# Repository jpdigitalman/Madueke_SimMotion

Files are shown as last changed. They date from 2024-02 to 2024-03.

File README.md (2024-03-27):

# Madueke_Sim (6DOF): Open Source ESP32 Controlled Servo Motor Board (AMC-AASD15A)

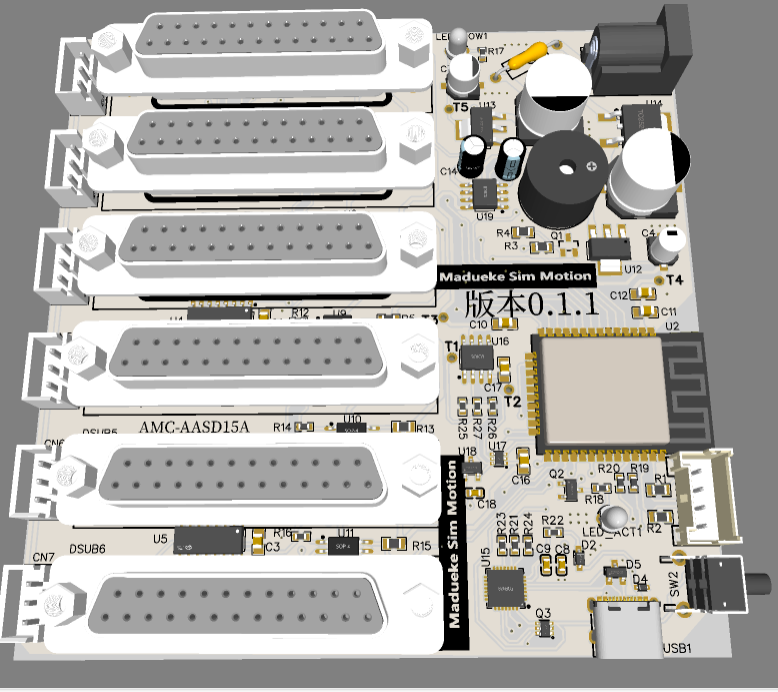
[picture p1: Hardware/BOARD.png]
Madueke_Sim Schematic


Welcome to Madueke_Sim (6DOF), an open-source project revolutionizing motion simulation! Our project utilizes the powerful ESP32 microcontroller to control six servo motors, providing a seamless and immersive experience for motion simulation enthusiasts.

## Features:

- **ESP32 Compatibility**: Our board is designed to seamlessly integrate with ESP32 microcontrollers, offering robust performance and versatility.
  
- **Plug and Play Servo Driver Support**: The board supports AASD-15A servo driver plug and play functionality, making setup a breeze.
  
- **Open Hardware**: We believe in transparency and collaboration. The board's schematic, PCB layout, and Bill of Materials (BOM) are all open-source, empowering users to customize and improve the design.

- **Versatile Firmware**: Our Arduino-based firmware supports various configurations, including 6-DOF, 3-DOF plus Yaw, and 4-DOF plus Yaw, catering to different motion simulation needs.

- **Sample Web Application**: Experience our motion simulation firsthand with our free source code for the firmware, which includes a sample web application. Test all motor movements effortlessly and explore the capabilities of Madueke_Sim (6DOF).

- **Advanced Firmware**: For enthusiasts seeking even more features, our advanced firmware, available upon request, supports popular motion simulation platforms like Simtools. Additionally, it includes built-in support for a range of games, from F1-2022 to Roller-Coaster Games, elevating your simulation experience to new heights.

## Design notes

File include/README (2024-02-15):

# Madueke_Sim (6DOF): Open Source ESP32 Controlled Servo Motor Board

Welcome to Madueke_Sim (6DOF), an open-source project revolutionizing motion simulation! Our project utilizes the powerful ESP32 microcontroller to control six servo motors, providing a seamless and immersive experience for motion simulation enthusiasts.

## Features:

- **ESP32 Compatibility**: Our board is designed to seamlessly integrate with ESP32 microcontrollers, offering robust performance and versatility.
  
- **Plug and Play Servo Driver Support**: The board supports AASD-15A servo driver plug and play functionality, making setup a breeze.
  
- **Open Hardware**: We believe in transparency and collaboration. The board's schematic, PCB layout, and Bill of Materials (BOM) are all open-source, empowering users to customize and improve the design.

- **Versatile Firmware**: Our Arduino-based firmware supports various configurations, including 6-DOF, 3-DOF plus Yaw, and 4-DOF plus Yaw, catering to different motion simulation needs.

- **Sample Web Application**: Experience our motion simulation firsthand with our free source code for the firmware, which includes a sample web application. Test all motor movements effortlessly and explore the capabilities of Madueke_Sim (6DOF).

- **Advanced Firmware**: For enthusiasts seeking even more features, our advanced firmware, available upon request, supports popular motion simulation platforms like Simtools and FlyTP Mover. Additionally, it includes built-in support for a range of games, from F1-2022 to Roller-Coaster Games, elevating your simulation experience to new heights.

## Get Involved:

Madueke_Sim (6DOF) is a community-driven project, and we welcome contributors of all backgrounds. Whether you're an experienced developer, a hardware enthusiast, or simply curious about motion simulation, there are plenty of ways to get involved:

- **Contribute Code**: Help us improve and expand our firmware by contributing code to our open-source repository.
  
- **Test and Provide Feedback**: Test our firmware and hardware setups, and share your feedback to help us refine and enhance the project.
  
- **Spread the Word**: Share Madueke_Sim (6DOF) with your friends, colleagues, and fellow enthusiasts. Together, we can build a vibrant community around motion simulation.

## Join Us:

Ready to dive into the world of motion simulation with Madueke_Sim (6DOF)? Join us on GitHub and start exploring today! Whether you're a seasoned developer or a newcomer to the scene, there's something for everyone in our open-source project. Let's innovate, collaborate, and push the boundaries of motion simulation together.

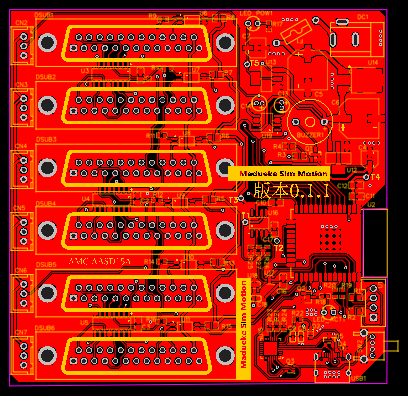
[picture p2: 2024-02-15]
Hardware/PCB_PCB_MaduekeSimV0.2_2024-02-15.png

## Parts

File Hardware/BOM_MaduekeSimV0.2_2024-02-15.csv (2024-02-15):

ID | Name | Designator | Footprint | Quantity | Manufacturer Part | Manufacturer | Supplier | Supplier Part | Price
1 | HMB1275-05B | BUZZER1 | BUZ-TH_BD12.0-P7.60-D0.6-FD | 1 | HMB1275-05B | HNDZ | LCSC | C96491 | 0.277
2 | 100nF | C1,C2,C3,C10,C11,C16,C17 | C0805 | 7 | CC0805KRX7R8BB104 | YAGEO | LCSC | C519981 | 0.006
3 | 22uF | C4 | CAP-SMD_BD4.0-L4.3-W4.3-LS5.1-FD | 1 | RVE1C220M0405 | ROQANG(容强) | LCSC | C131114 | 0.023
4 | 220uF | C5,C6 | CAP-SMD_BD10.0-L10.3-W10.3-LS11.3-FD | 2 | UWT1H221MNL1GS | Nichicon(尼吉康) | LCSC | C125977 | 0.189
5 | 22uF | C7 | CAP-SMD_BD5.0-L5.3-W5.3-FD | 1 | VT1E220M0505 | ROQANG | LCSC | C239255 | 0.03
6 | 4.7uF | C8 | C0603 | 1 | 0603X475K160NT | FH | LCSC | C99229 | 0.011
7 | 100nF | C9 | C0603 | 1 | CL10B104KO8NNNC | SAMSUNG | LCSC | C66501 | 0.003
8 | 22uF | C12 | C0805 | 1 | CL21A226KQQNNNE | SAMSUNG | LCSC | C87997 | 0.039
9 | 10uF | C13,C14 | CAP-TH_BD4.0-P1.50-D0.8-FD | 2 | KS106M025C07RR0VH2FP0 | CX(承兴) | LCSC | C43351 | 0.009
10 | 470nF | C18 | C0603 | 1 | CC0603KRX7R7BB474 | YAGEO(国巨) | LCSC | C106851 | 0.01
11 | XH-3A | CN2,CN3,CN4,CN5,CN6,CN7 | CONN-TH_XH-3A | 6 | XH-3A | BOOMELE(博穆精密) | LCSC | C2316 | 0.009
12 | BAT760-7 | D2 | SOD-323_L1.8-W1.3-LS2.5-RD | 1 | BAT760-7 | DIODES | LCSC | C124187 | 0.028
13 | LESD5D5.0CT1G | D4 | SOD-523_L1.2-W0.8-LS1.6-BI | 1 | LESD5D5.0CT1G | Leshan Radio | LCSC | C383211 | 0.019
14 | BST23C032V | D5 | SOT-23_L2.9-W1.3-P1.90-LS2.4-BR | 1 | BST23C032V | Bourne Semicon (Shenzhen) | LCSC | C151968 | 0.062
15 | DC-005-5.5*2.1 | DC1 | DC-IN-TH_DC-005-2 | 1 | DC-005-5.5*2.1 | null | LCSC | C9900017044
16 | FDB2503-F0DS300K6KF | DSUB1,DSUB2,DSUB3,DSUB4,DSUB5,DSUB6 | DB25-TH_FDB2503-F0DS300K6KF | 6 | FDB2503-F0DS300K6KF | TXGA(特思嘉) | LCSC | C2834383 | 1.041
17 | 2F3.15A 250V | F1 | FUSE-TH_BD2.7-L7.3-P11.30-D0.6 | 1 | 2F.3150212000R1B02 | xcfuse(旭程) | LCSC | C140541 | 0.072
18 | i2cData | LED_ACT1,LED_POW1 | LED-TH_BD3.8-P2.54-RD | 2 | TZ-L2-03YYBYG1GDJ30-001 | TUOZHAN(拓展光电) | LCSC | C779431 | 0.024
19 | L2N7002KLT1G | Q1 | SOT-23-3 | 1 | L2N7002SLT1G | LRC | LCSC | C250818 | 0.015
20 | PDTD123TT,215 | Q2 | SOT-23-3_L2.9-W1.6-P1.90-LS2.8-BR | 1 | PDTD123TT,215 | Nexperia(安世) | LCSC | C168870 | 0.053
21 | UMH3N | Q3 | SC-70-6_L2.2-W1.3-P0.65-LS2.1-BR | 1 | UMH3N | CJ | LCSC | C62892 | 0.048
22 | 4.7kΩ | R1,R2,R5,R6,R7,R8,R13,R15 | R0805 | 8 | 0805W8J0472T5E | UniOhm | LCSC | C26022 | 0.002
23 | 330 | R3 | R0805 | 1 | AC0805FR-07330RL | YAGEO | LCSC | C144564 | 0.004
24 | 10kΩ | R4 | R0805 | 1 | TR0805D10KP0550 | Ever Ohms Tech | LCSC | C332266 | 0.008
25 | 330Ω | R9,R10,R11,R12,R14,R16,R17,R18 | R0603 | 8 | RS-03K331FT | FH | LCSC | C125768 | 0.001
26 | 0Ω | R19,R20 | R0603 | 2 | RS-03000FT | FH | LCSC | C136582 | 0.001
27 | 2kΩ | R21 | R0603 | 1 | RS-03K2001FT | FH | LCSC | C115336 | 0.001
28 | 22.1kΩ | R22 | R0603 | 1 | RS-03K2212FT | Guangdong Fenghua Advanced Tech | LCSC | C310274 | 0.001
29 | 10kΩ | R23 | R0603 | 1 | RS-03K1002FT | Guangdong Fenghua Advanced Tech | LCSC | C115324 | 0.001
30 | 47.5kΩ | R24 | R0603 | 1 | 0603WAF4752T5E | UniOhm | LCSC | C23061 | 0.001
31 | 11kΩ | R25 | R0603 | 1 | ARG03FTC1102 | Viking(光颉) | LCSC | C217703 | 0.007
32 | 8.25kΩ | R26 | R0603 | 1 | RT0603BRD078K25L | YAGEO(国巨) | LCSC | C705798 | 0.03
33 | 33kΩ | R27 | R0603 | 1 | RT0603BRD0733KL | YAGEO(国巨) | LCSC | C705768 | 0.03
34 | GT-TC193A-H0675-L1 | SW2 | SW-TH_GT-TC193A-H0675-L1 | 1 | GT-TC193A-H0675-L1 | G-Switch(品赞) | LCSC | C2835017 | 0.134
35 | B04B-XASK-1(LF)(SN) | U1 | CONN-TH_B04B-XASK-1-LF-SN | 1 | B04B-XASK-1(LF)(SN) | JST Sales America | LCSC | C264994 | 0.058
36 | ESP32-WROOM-32E(4MB) | U2 | WIFI-SMD_ESP32-WROOM-32E | 1 | ESP32-WROOM-32E(4MB) | Espressif Systems | LCSC | C701341 | 2.993
37 | AM26LS31CDR | U3,U4,U5 | SOIC-16_L9.9-W3.9-P1.27-LS6.0-BL | 3 | AM26LS31CDR | TI(德州仪器) | LCSC | C6179 | 0.388
38 | EL3H7(B)(TA)-G | U6,U7,U8,U9,U10,U11 | SOP-4_L4.4-W2.8-P1.27-LS7.0-TL | 6 | EL3H7(B)(TA)-G | EVERLIGHT(亿光) | LCSC | C32565 | 0.065
39 | AMS1117-3.3_C5181460 | U12 | SOT-223-3_L6.4-W3.5-P2.30-LS7.0-BR | 1 | AMS1117-3.3 | HX(恒佳兴) | LCSC | C5181460 | 0.033
40 | AMS1117-5.0 | U13 | SOT-223_L6.5-W3.5-P2.30-LS7.0-BR | 1 | AMS1117-5.0 | AMS | LCSC | C6187 | 0.169
41 | 78D12AL-TN3-R | U14 | TO-252-2_L6.5-W6.1-P4.58-LS10.0-TL | 1 | 78D12AL-TN3-R | UTC(友顺) | LCSC | C73290 | 0.159
42 | CP2102-GMR | U15 | QFN-28_L5.0-W5.0-P0.50-BL-EP | 1 | CP2102-GMR | SILICON LABS | LCSC | C6568 | 2.13
43 | OPA188AIDR | U16 | SOIC-8_L4.9-W3.9-P1.27-LS6.0-BL | 1 | OPA188AIDR | TI(德州仪器) | LCSC | C85166 | 1.758
44 | MCP4018 | U17 | SC-70-6_L2.2-W1.3-P0.65-LS2.1-BR | 1 | MCP4018T-503E/LT | MICROCHIP(美国微芯) | LCSC | C145561 | 1.378
45 | REF3025AIDBZR | U18 | SOT-23-3_L2.9-W1.6-P1.90-LS2.8-BR | 1 | REF3025AIDBZR | TI(德州仪器) | LCSC | C11334 | 0.414
46 | TC7660SEOA713 | U19 | SOIC-8_L4.9-W3.9-P1.27-LS6.0-BL | 1 | TC7660SEOA713 | MICROCHIP(美国微芯) | LCSC | C144305 | 2.119
47 | TYPE-C 16PIN 2MD(073) | USB1 | USB-C-SMD_TYPE-C-6PIN-2MD-073 | 1 | TYPE-C 16PIN 2MD(073) | SHOU HAN(首韩) | LCSC | C2765186 | 0.056

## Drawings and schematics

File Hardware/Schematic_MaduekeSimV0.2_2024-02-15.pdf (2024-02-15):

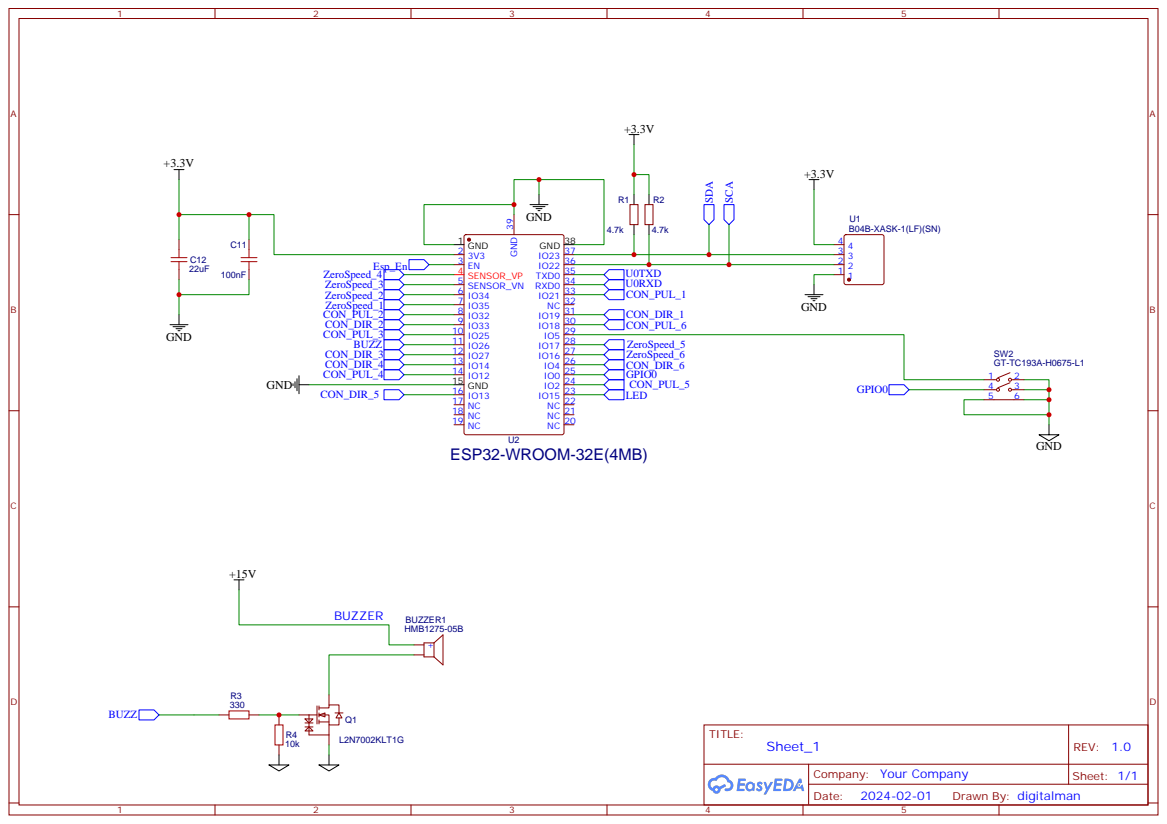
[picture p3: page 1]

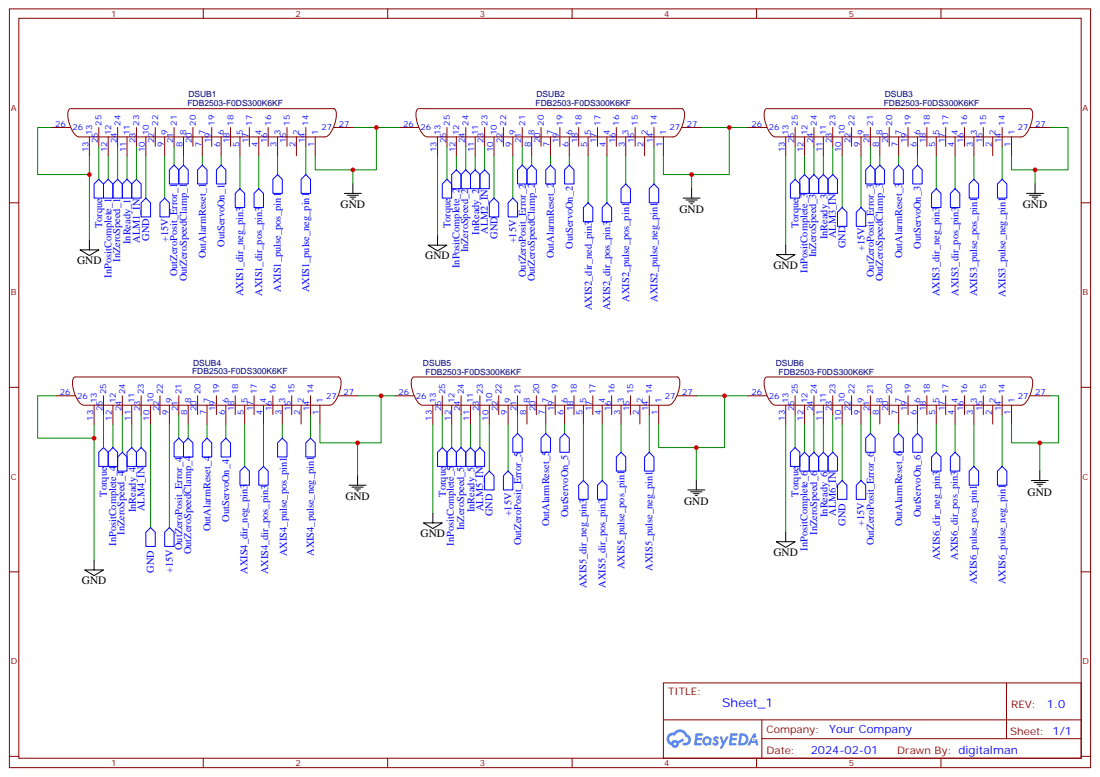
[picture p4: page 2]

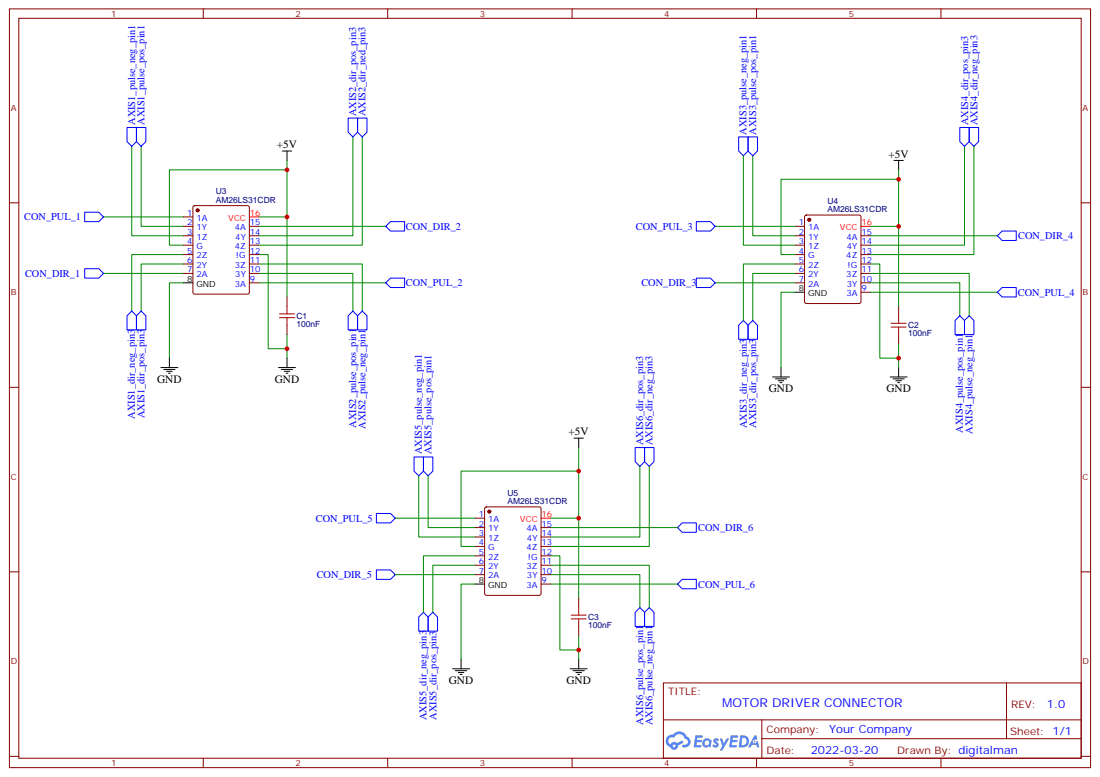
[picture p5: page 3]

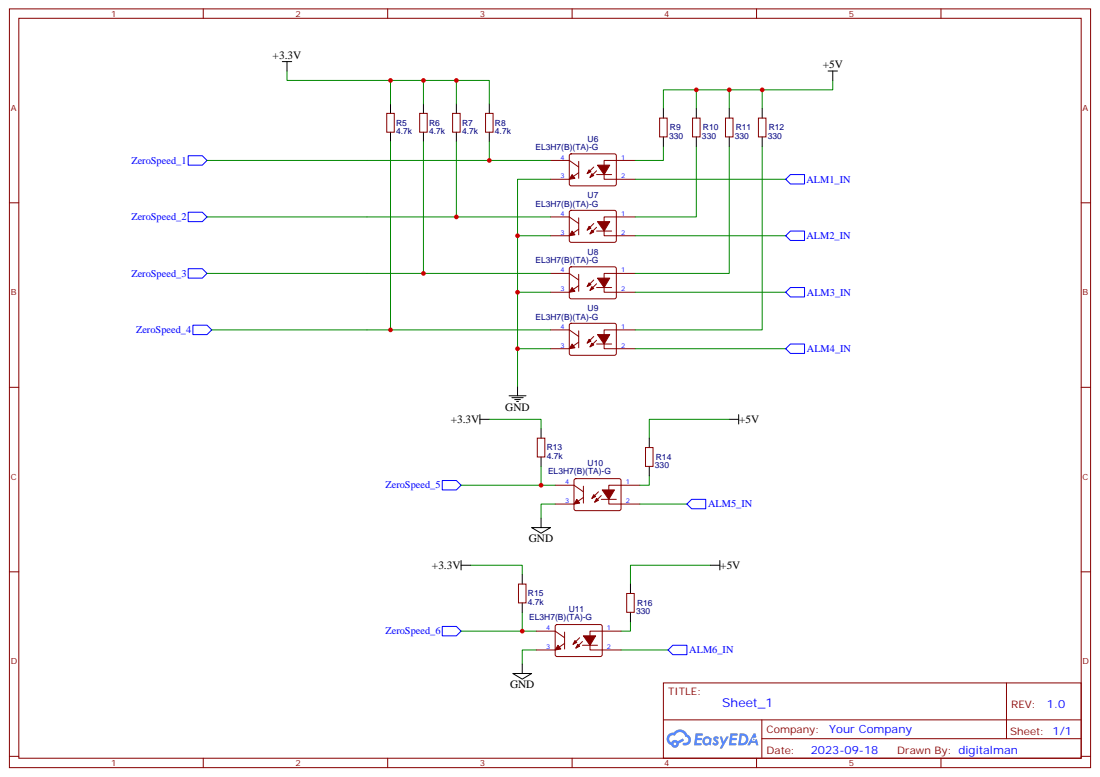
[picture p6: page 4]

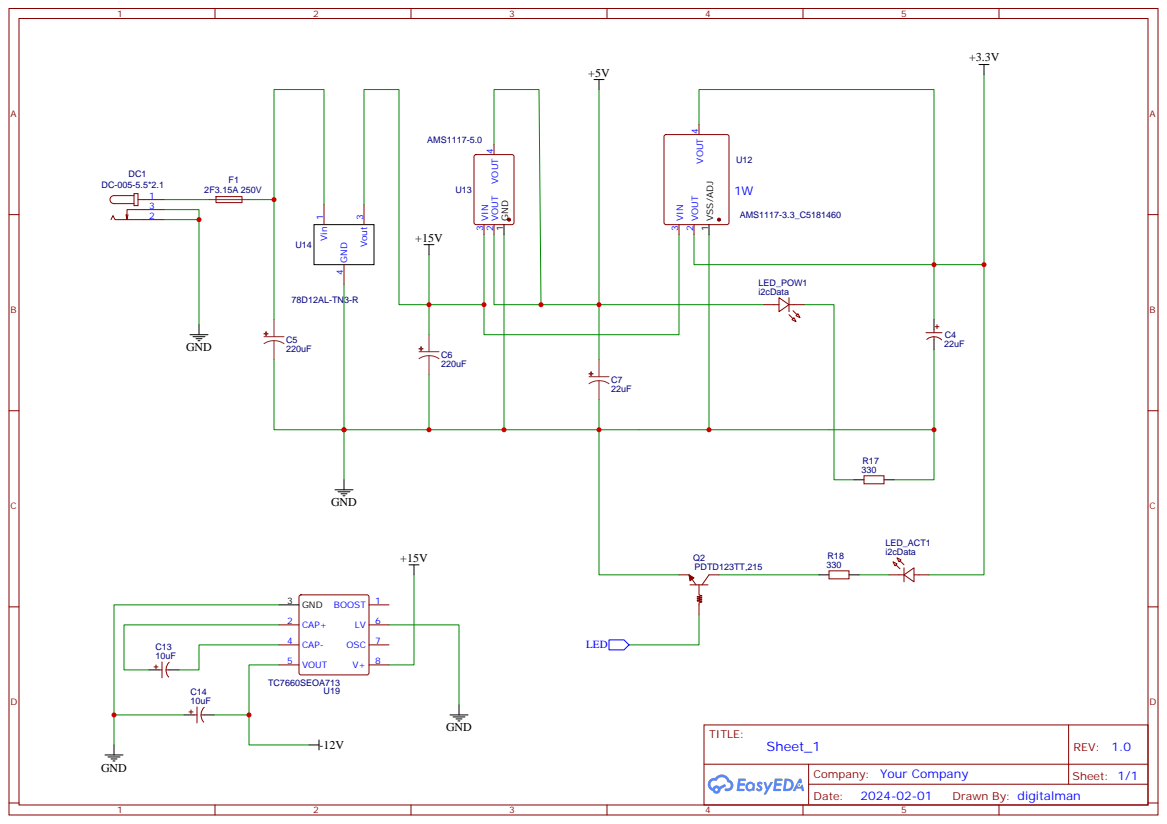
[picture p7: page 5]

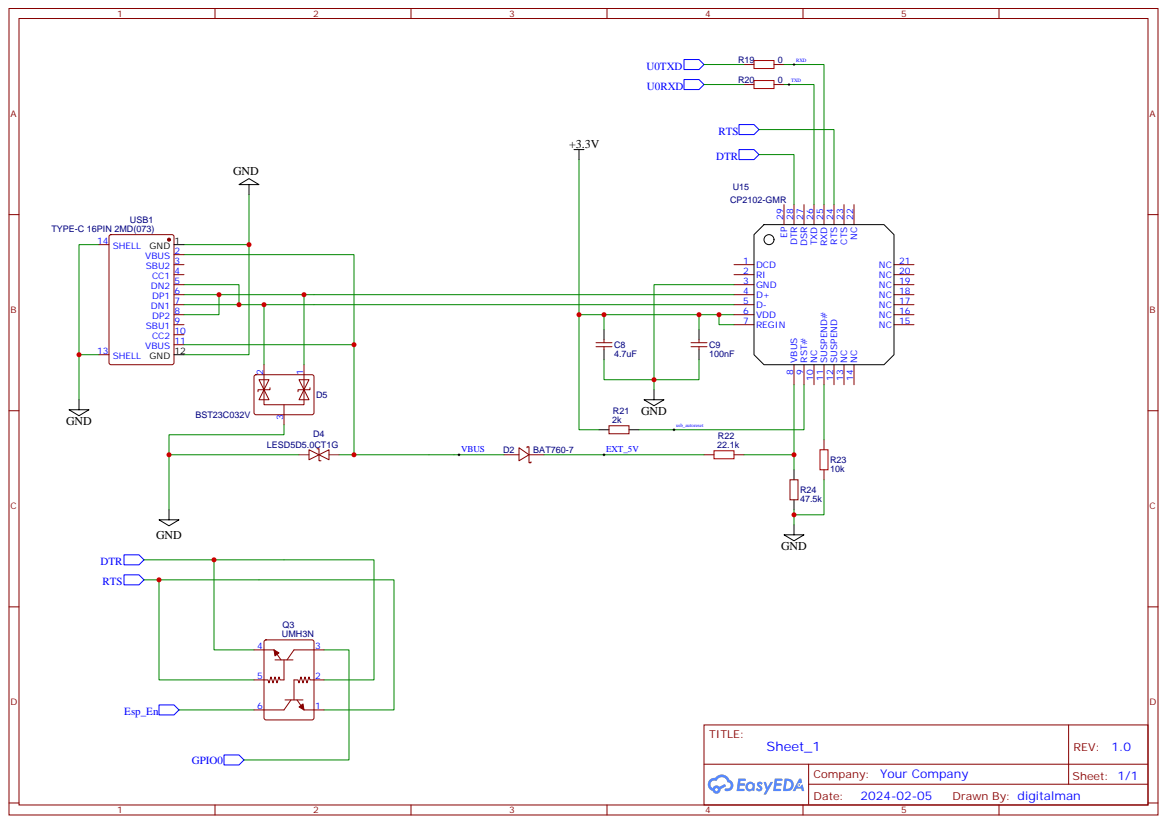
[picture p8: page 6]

NC 22 CTS 23 RTS 24 RXD 25 TXD 26 DSR 27 DTR 28 EP 29

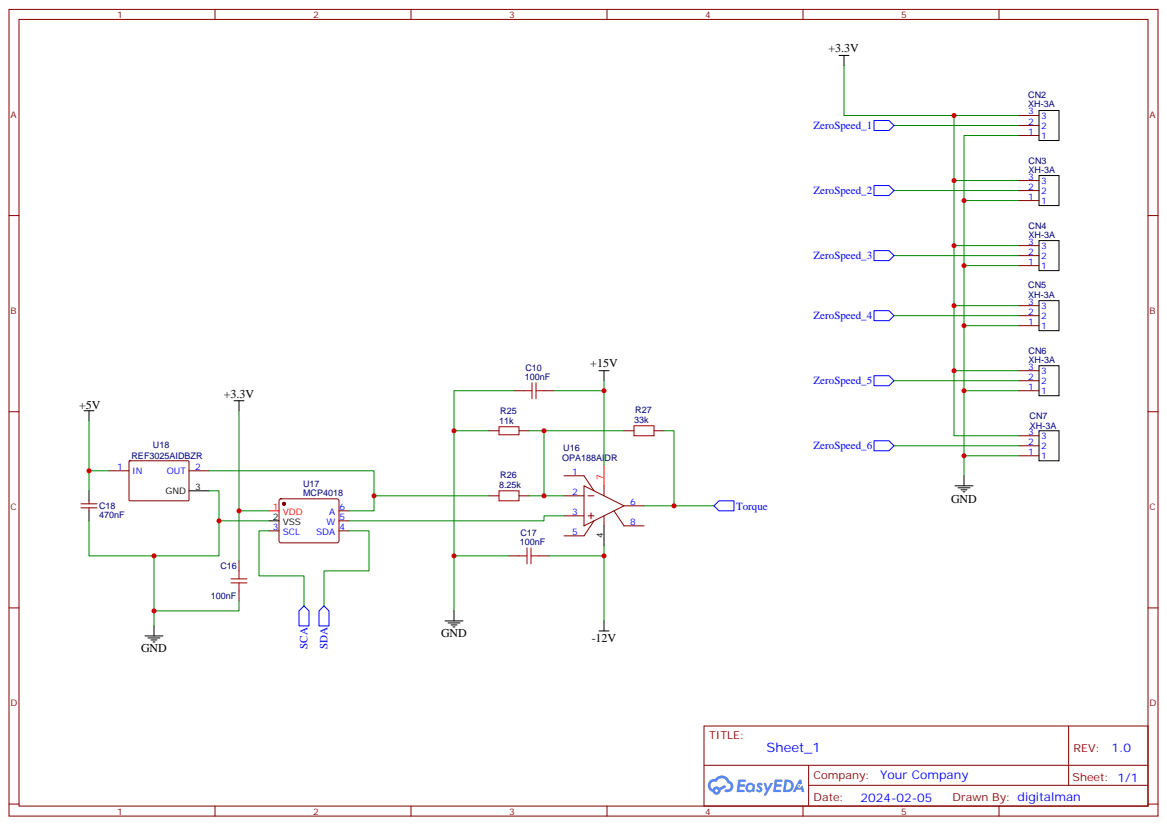
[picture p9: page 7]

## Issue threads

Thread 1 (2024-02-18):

It is suport step/dir interface??

artayasa, 2024-02-18:
Hi sir.
Thank you for ypur great prohect.
It is posible to used ac servo with step dir??
Or pwm cw ccw?? Or analog sir?? Because i have a coustem servo driver with 2000ppr encorder woth step/dir interface. I dont know how do u control the servo by witchone interface. Thank u.

jpdigitalman, 2024-02-19:
Yes, it uses step / dir in

Check the DSUB Connector Pins.

(pin 4 is direction+, pin 5 is direction -)
(pint 3 is pulse+, pin 14 is pulse-)

artayasa, 2024-02-19:
> (pin 4 is direction+, pin 5 is direction -)
> (pint 3 is pulse+, pin 14 is pulse-)

So that mean work with my driver are suport step/dir right?? How about step/rev sir? Already fix or can adjust on the web sir..
So its meas suport stepper also sir? If yes i want to try mini with stepper first sir.
Thank u for your great project🙏

jpdigitalman, 2024-02-20:
Yes, it uses step / dir.

yes it supports stepper.

artayasa, 2024-02-20:
How about other pin like a zero speed, out zero post and etc sir?? Posible not used???

And how about step/rev like i have stepper with 1.8deg so its mean 200step/rev sir. Need to spesific step/rev??
Because i loking video for ypur project nothing sir on youtube.

jpdigitalman, 2024-02-20:
Did you check the schematics I provided before asking about other pins?

 If you want to use 200step/rev motor, you modify the number of steps in code.

Have you checked out the code to understand how it works?

 Not sure you understand how stepper motor calibration works.

Why are you looking video of my project on YouTube?

I didn't add any video link.

Closed 2024-02-20.

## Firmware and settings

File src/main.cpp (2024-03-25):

#include <Arduino.h>

#include <debug.h>

#include <settings.h>
#include <board.h>
#include <pulsefast.h>
#include <simulator.h>
#include <network.h>

void setup() {

  initSerial();

  initPins();

  buzzBeep();

  pulse_setup();

  networksetup();
  
  home_return();

}

void loop() {
  
  //ledFlash();
  //buzzBeep();

  pulse_refresh();

  home_return();
    
}

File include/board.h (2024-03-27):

/**
 * @brief 
 * 
 */
void ledFlash();
void buzzBeep();


void initPins(){
    pinMode(LED, OUTPUT);
    digitalWrite(LED, LOW);

    pinMode(buzzerPin, OUTPUT);
    digitalWrite(buzzerPin, LOW);

    pinMode(i_button, INPUT_PULLUP); //check
    pinMode(boot_button, INPUT_PULLUP); //check

    //Alarm input means no movement allowed
    //Low Active
    pinMode(alarm_1, INPUT);
    pinMode(alarm_2, INPUT);
    pinMode(alarm_3, INPUT);
    pinMode(alarm_4, INPUT);
    pinMode(alarm_5, INPUT);
    pinMode(alarm_6, INPUT);

    pinMode(CON_PUL_1, INPUT);
    pinMode(CON_PUL_2, INPUT);
    pinMode(CON_PUL_3, INPUT);
    pinMode(CON_PUL_4, INPUT);
    pinMode(CON_PUL_5, INPUT);
    pinMode(CON_PUL_6, INPUT);

    pinMode(CON_DIR_1, INPUT);
    pinMode(CON_DIR_2, INPUT);
    pinMode(CON_DIR_3, INPUT);
    pinMode(CON_DIR_4, INPUT);
    pinMode(CON_DIR_5, INPUT);
    pinMode(CON_DIR_6, INPUT);
}

/// @brief 
void initSerial(){
    Serial.begin(115200);  
    delay(250);
    Serial.println("SimMotion Startup..");
}

/// @brief 
void ledFlash() {
  unsigned long currentMillis = millis();
  if (currentMillis - previousMillis >= interval) {
    previousMillis = currentMillis;
    interval = random(500, 2000);
    digitalWrite(LED, !digitalRead(LED));
  }
}

void buzzON(){
  digitalWrite(buzzerPin, HIGH);
}
void buzzOFF(){
  digitalWrite(buzzerPin, LOW);
}
/// @brief beep
void buzzBeep(){
  unsigned long currentMillis = millis();
  if (currentMillis - buzzerPreviousMillis >= buzzerInterval) {
    buzzerPreviousMillis = currentMillis;
    buzzerInterval = random(500, 1000);  // 

    // Activate the buzzer for a short duration
    buzzON();
    delay((int)buzzerInterval);  //
    buzzOFF();
  }
}

/// @brief do nothing
void NP(){
    return;
}

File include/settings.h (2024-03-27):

#define no_alarm false

#define i60k 60000
#define i100k 100000
#define i200k 200000

unsigned long previousMillis = 0;  // will store the last time the LED was updated
unsigned long interval = 0;  // interval at which to blink (initialized to 0 for first run)
unsigned long buzzerPreviousMillis = 0;
unsigned long buzzerInterval = 0;

#define full_step 1000  //number of full cylinder steps
#define LED 15
#define buzzerPin 26

#define i_button 5
#define boot_button 0

#define alarm_1 35
#define alarm_2 34
#define alarm_3 39
#define alarm_4 36
#define alarm_5 17
#define alarm_6 16

#define CON_PUL_1 21
#define CON_DIR_1 19

#define CON_PUL_2 32
#define CON_DIR_2 33

#define CON_PUL_3 25
#define CON_DIR_3 27

#define CON_PUL_4 12
#define CON_DIR_4 14

#define CON_PUL_5 2
#define CON_DIR_5 13

#define CON_PUL_6 18
#define CON_DIR_6 4

const uint32_t PWM_Pins[]   = { CON_PUL_1, CON_PUL_2, CON_PUL_3, CON_PUL_4, CON_PUL_5, CON_PUL_6 };
const uint32_t DIR_Pins[]   = { CON_DIR_1, CON_DIR_2, CON_DIR_3, CON_DIR_4, CON_DIR_5, CON_DIR_6 };

const int yaw_max_frequency = 20000; //30khz ==> max rpm for yaw
const int pr_max_frequency = i200k; //100khz ==> max rpm for PRs
const int accelMax = yaw_max_frequency; //accel /decel

long oldangle_yaw[7];// =   { 0, 0, 0, 0 }; //oldangle = 0.0f
float phase_a_ct, oldphase_a_ct, phase_b_ct, oldphase_b_ct, phase_c_ct, oldphase_c_ct, phase_d_ct, phase_e_ct, phase_f_ct = 0.00f;

int zero_movement[7];
int zero_movement_old[7];
bool errorflag = true; //start with error flag on and reset automatically after initialization
bool force = true;

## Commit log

2024-02-15 new file: Hardware/Altium_Designer_MaduekeSimV0.2_2024-02-15/AlarmIn.schdoc new file: Hardware/Altium_Designer_MaduekeSimV0.2_2024-02-15/DSUB.schdoc new file: Hardware/Altium_Designer_MaduekeSimV0.2_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
    [AlarmIn.schdoc, BOM_MaduekeSimV0.2_2024-02-15.csv, DSUB.schdoc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]
2024-02-15 PCB 3D: Hardware/BOARD.png
2024-03-25 modified: include/board.h modified: include/network.h modified: include/pulsefast.h modified: include/settings.h modified: src/main.cpp
2024-03-27 modified: include/board.h
